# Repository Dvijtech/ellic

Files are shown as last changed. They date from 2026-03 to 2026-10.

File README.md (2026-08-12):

# 🤖 ELLIC 🚶‍♂️

Мы делаем экспериментальный формат медиалиги мех-спорта, где команды строят человекоуправляемые машины и участвуют в боях в дополненной реальности ⚔️

<table> 
  <tr> 
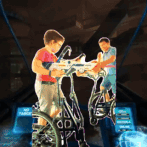
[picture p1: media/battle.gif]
   <td>  </td> 
  </tr> 
</table>

Как BattleBots, только ты внутри мехбота 🤯  
Ты ходишь в механическом экзоскелете и дерёшься в AR.

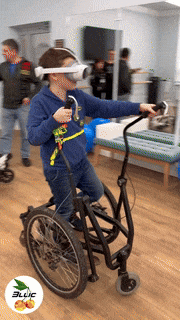
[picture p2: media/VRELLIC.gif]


🔬 Это открытый инженерный эксперимент - смесь спорта, игры и инженерного челленджа 🎮⚙️

Для создания мехботов используется платформа ELLIC, где пилот шагает внутри машины, а сам мехбот по цене сопоставим с электровелосипедом 🚲  

<table>
  <tr>
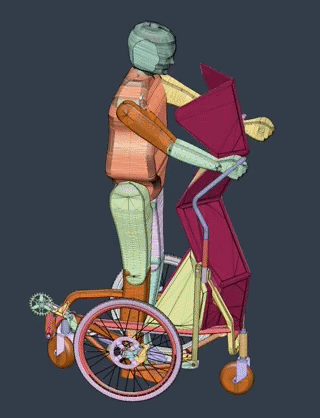
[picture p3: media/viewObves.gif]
    <td></td>
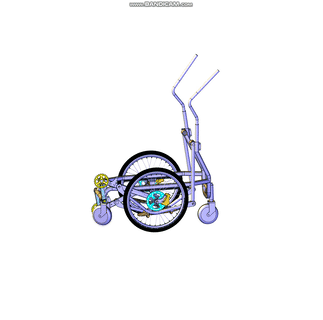
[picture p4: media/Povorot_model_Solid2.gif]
    <td></td>
  </tr>
</table>

В этом репозитории выложены наши разработки, необходимые для создания своего мехбота, и описан экспериментальный формат соревнований в дополненной реальности 📦  

---

# 🧩 Платформа состоит из трёх составляющих:

---

## 1. ⚙️ Физическая платформа. Модели и рабочая документация собраны в ⚙️ [cad/](cad/)

За основу взят эллипс из тренажёрного зала, поставлен на колёса — теперь в нём можно шагать и кататься 🏃‍♂️

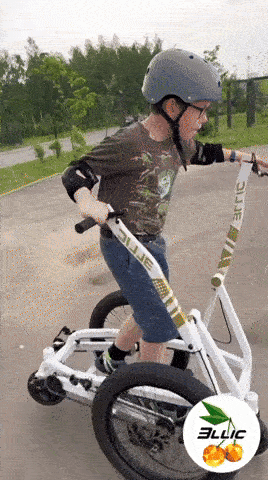
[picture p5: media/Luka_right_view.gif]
walking prototype


- [cad/MECHANISM.md](cad/MECHANISM.md) — описание устройства
  
- [cad/BUILD_ONE](cad/BUILD_ONE.md)  — описание сборки  

Содержимое репозитория:
- a. В репозитории представлены модели Ellic версии 14 в формате Fusion, SolidWorks, STEP  
- b. В папке **Дизайн** представлена модель фронтального обвеса мехбота  
- c. По запросу может быть предоставлена документация для сборки в формате ЕСКД 📄  
- d. Weapon 🔫  
  - виртуальные орудия (как сейчас)  
  - планируются пневматические пушки, стреляющие безопасными снарядами (например, для бассейна) 💦  
  - возможны роборуки для манипуляций, если мы придумаем для них правила 🤖  

---

## 2. 🔌 Электроника. Управляющее программное обеспечение в 📟 [firmware/](firmware/)

- моторы, помогающие движению ⚡  
- датчики момента (усилия на рычагах)  
- энкодер положения вала  
- датчики тока  
- джойстик 🎮  
- система управления (ESP32)  

Содержимое репозитория:
- a. Исходный код прошивки для управления моторами с джойстика 💻  

---

 ## 3. 🥽 [VR / AR лежит здесь:](https://github.com/loguluk/ELLIC)

VR-гарнитура для проведения битвы мехботов в формате дополненной реальности — с виртуальным или реальным противником 👾  

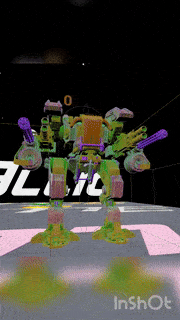
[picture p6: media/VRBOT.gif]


Содержимое репозитория:
- a. Исходный код на Unreal Engine 5.3 (в `.zip`)  
- b. `.apk` для PICO 4 (AR, технология see-through)  
  - бой с виртуальным противником  
  - стрельба ведётся тем же джойстиком, что управляет скутером 🔫  
- c. Папка **Чемп** — проект правил соревнований и безопасности 📜  

---

## Прочие материалы

## 🤖 Моделирование 📊 simulation/

Разделы для моделирования в среде:
- ROS  
- URDF  
- Webots  

Пока там только первые тесты и ничего финального 🧪  

---

## 🔬 Research 📝 [research/](research/) 

Материалы исследований по разным направлениям:
- a. Отчёт по гранту Фонда содействия инновациям  
- b. Медицинские исследования и гипотезы 🧠

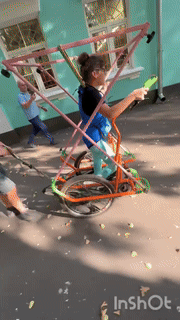
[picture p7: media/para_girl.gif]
 

[История проекта здесь](docs/history/ellicDevHistory.md).

---

## 👥 Community [community/](community/)

[START_A_TEAM](community/START_A_TEAM.md) - принципы формирования и вознаграждения команд медачемпионата

---

# ❓ Зачем тебе сюда

- хочешь построить меха → тебе сюда 🤖  
- хочешь участвовать в шоу → тебе сюда 🎬  
- хочешь просто играть → пока рано ⏳  

---

# ❗ Будет сложно, но мы поможем

В командах приветствуются навыки и оборудование:

- Производство медиаконтента 🎥  
- Знание Unreal Engine или Unity (как плюс, но не обязательно 🎮)  
- Геймдизайн  
- Работа с металлом (резка, сверление, сварка, лазер, гибка), механическая сборка 🔩  
- ESP32 или аналоги  
- знание велокомпонентов (как плюс 🚴)  

---

## ⚠️ Безопасность [chemp/Safety_rules.pdf](CHEMP/Safety_rules.pdf)

Мы тестируем систему и вводим правила безопасности, но это всё ещё экспериментальная техника ⚠️  

Всегда тестируйте:
- на низкой скорости  
- с доступной аварийной остановкой 🛑  

---

Это первый прототип реального мехспорта, и нет гарантии, что всё сразу будет работать идеально, но если это сработает хотя бы частично, вы получите:

- опыт создания реального мехбота: механика, электроника и интеграция с VR 🤖  
- эмоции от управления реальным мехом в бою 🔥  
- место в создании нового медиапродукта на стыке MEDIA – STEM – VR 🚀  

---

# 🎯 Цель

Сформировать в 2026 году 3–4 команды и провести экспериментальный медиачемпионат битвы мехботов:
проект правил здесь [chemp/](CHEMP/)

- чемпионат на вылет  
- 2 меха на спортивной площадке  
- бой в дополненной реальности  
- параллельная трансляция:  
  - физического мира  
  - AR-сцены 📡  

Мы можем предоставить готовые машины для соревнований. Машины могут быть доработаны командами по согласованному регламенту (мы за интересный и зрелищный движ) 😎  

[**MANUAL**](docs/Manual_EllicV14_EN.pdf)

Команды могут строить мехботов самостоятельно. При необходимости мы можем предоставить отдельные сложные детали (рамы, тяги, рычаги) 🏗️  
[cad/BUILD_ONE](cad/BUILD_ONE.md) 

---

## 🚀 Как вписаться без боли

**Быстрый вход (без сборки меха):**

- мы даём готовые машины  
- можно прийти и тестировать  
- можно просто участвовать как пилот 🧑‍🚀  
- можно зайти как команда без инженерки  

Смотри подробнее в [community/START_A_TEAM](community/START_A_TEAM.md) 📄  

---

## 🎁 Что ты реально получишь

- участие в первом прототипе мехспорта  
- видео / медиа с боя 🎥  
- опыт пилотирования меха  
- возможность стать частью команды-основателя 🤝  

---

## 📫 Контакты

Я — Дмитрий Логунов. Раньше занимался автоматизацией в госсекторе и промышленности. Несколько лет со своими сыновьями я делаю Ellic — платформу, на которой человек шагает внутри машины 🤖  

Это не идеальная система и не готовый продукт, а живая разработка, которую мы ведём прямо сейчас 🔧  

Проект развивается в рамках ООО «Движ.Тех» — небольшой компании, занимающейся образовательной робототехникой и экспериментальными платформами 🏢  

Проект поддержан Фондом содействия инновациям 💡  

📧 dselog@gmail.com

[START_A_TEAM](START_A_TEAM.md)

<a href="https://github.com/yourusername/yourrepo/stargazers" target="_blank" style="text-decoration:none;">
  <kbd>⭐ Star the repository</kbd>
</a>

<a href="https://github.com/yourusername/yourrepo/fork" target="_blank" style="text-decoration:none;">
  <kbd>🔧 Fork the project</kbd>
</a>

<a href="https://github.com/yourusername/yourrepo/issues" target="_blank" style="text-decoration:none;">
  <kbd>💡 Open issues with ideas</kbd>
</a>

<a href="https://twitter.com/intent/tweet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" target="_blank" style="text-decoration:none;">
  <kbd>📢 Share the project</kbd>
</a>

---

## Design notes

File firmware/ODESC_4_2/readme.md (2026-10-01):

# ODESC 4.2 — ввод в работу нового ODrive (ELLIC)

Ожидаемо: прошивка **0.5.6**, железо **3.6**, протокол **CAN Simple**, 250000 бит/с, мотор на **axis0**, энкодер — Hall (mode 1, cpr 42).

Файлы в этой папке:

| Файл | Что это |
|---|---|
| `configODRIVE.txt` | **Шаблон** (бэкап рабочего ODrive, node_id=1). Содержит калибровку старого мотора — как есть на новый не заливать |
| `make_config.py` | Делает из шаблона безопасный конфиг для пусконаладки с нужным node_id |
| `backups/` | Итоговые бэкапы каждого откалиброванного ODrive (по одному файлу на плату) |

> В командах ниже объект называется `dev0` (как в прежних заметках). Если в твоём шелле он `odrv0` — подставь.

---

## Почему так, а не «залить как есть»

Конфиг стоит переносить (лимиты, усиления, CAN-рейты, Hall-режим одинаковы для всей партии). Но в нём есть **данные конкретного мотора**: `phase_resistance`, `phase_inductance`, `phase_offset`, `hall_polarity`, флаги `pre_calibrated`. Их надо измерить заново на каждом новом моторе, иначе это риск плохого момента и рывков.

Две ловушки, которые закрывает `make_config.py`:

1. Если флаги `pre_calibrated` остались `True`, `FULL_CALIBRATION_SEQUENCE` **пропустит** калибровку.
2. В шаблоне `startup_closed_loop_control = true` — после рестора плата сразу включит замкнутый контур на чужой калибровке, и мотор может дёрнуться. В конфиге для пусконаладки это выключено, включаем в самом конце.

---

## Перед началом (1 минута)

- Колесо/мотор **без нагрузки**: колесо приподнято, ничего не касается. Калибровка вращает мотор.
- Питание силовое (аккумулятор/блок), не только USB.
- К ПК по USB подключён **один** ODrive. CAN к ESP32 пока **не подключён** (чтобы не было двух плат с одинаковым node_id на шине).
- Версия `odrivetool` та же, что использовалась для `backup-config` на старой плате.

---

## Шаг 1. Прошивка (только для чистой платы)

Через программатор залить `firmware.elf`. 

Затем в `odrivetool`:

```python
print(f"{dev0.fw_version_major}.{dev0.fw_version_minor}.{dev0.fw_version_revision}")   # ждём 0.5.6
print(f"{dev0.hw_version_major}.{dev0.hw_version_minor}")                              # ждём 3.6
print(hex(dev0.serial_number))                                                         # запиши — пригодится для имени бэкапа
```

## Шаг 2. Сделать конфиг под нужный node_id

В терминале (не в odrivetool), в папке с `configODRIVE.txt`:

```
python make_config.py 1     # RIGHT  -> config_node1_commissioning.json
python make_config.py 2     # LEFT   -> config_node2_commissioning.json
```

RIGHT = node_id 1, LEFT = node_id 2 (как в спецификации).

## Шаг 3. Залить конфиг

```
odrivetool restore-config config_node2_commissioning.json
```

Плата перезагрузится и сохранит конфиг. Затем открыть `odrivetool` заново и проверить:
Предупреждения Could not restore ... anticogging.calib_anticogging / cogging_ratio / index безвредны: это служебные поля антикоггинга, которые odrivetool 0.5.4 не умеет записывать через exchange. Антикоггинг ты не используешь (pre_calibrated: false), так что на работу они не влияют. Итоговые строки «Some of the configuration could not be restored» и «Configuration restored» ожидаемы. Второй запуск был не нужен, но ничему не повредил.

Последняя команда restore-config config_node1_commissioning.json внутри IPython (In [2]:) не сработает. Это команда терминала, а не Python. Тебе она там уже не нужна, она выполнена. Строку v в In [1] можно проигнорировать.

Оболочка уже открыта и подключена как dev0, так что команды из readme.md подходят без замены. Дальше, шаг 3 (проверки после рестора), вставь в оболочку:

```python
print(dev0.axis0.config.can.node_id)                       # нужный node_id
print(dev0.can.config.baud_rate)                           # 250000
print(dev0.axis0.config.startup_closed_loop_control)       # False (пока)
print(dev0.axis0.controller.config.vel_limit, dev0.axis0.motor.config.current_lim)   # 2.0 10.0
```

Если `restore-config` ругается на отдельные поля — это обычно read-only параметры, на работу не влияет. Критично, чтобы совпали проверки выше.

## Шаг 4. Калибровка (мотор свободен! минимум 37 вольт и 2 ампера на блоке питания. При малых токах не калибруется!!)

```python
# 4.1 Параметры мотора
dev0.axis0.requested_state = AXIS_STATE_MOTOR_CALIBRATION
# подождать ~5 с, пока мотор пискнет/затихнет
print(dev0.axis0.error, dev0.axis0.motor.error)            # оба 0
print(dev0.axis0.motor.config.phase_resistance, dev0.axis0.motor.config.phase_inductance)
#   ориентир со старой платы: R ≈ 0.176, L ≈ 0.000204 (±~20% нормально; в разы — стоп, проверять фазы)
dev0.axis0.motor.config.pre_calibrated = True

# 4.2 Hall: полярность, затем смещение (мотор повернётся на несколько оборотов)
dev0.axis0.requested_state = AXIS_STATE_ENCODER_HALL_POLARITY_CALIBRATION
dev0.axis0.requested_state = AXIS_STATE_ENCODER_OFFSET_CALIBRATION
# подождать ~10 с
print(dev0.axis0.error, dev0.axis0.encoder.error)          # оба 0
print(dev0.axis0.encoder.config.hall_polarity_calibrated)  # True
print(dev0.axis0.encoder.is_ready)                         # True
print(dev0.axis0.encoder.config.phase_offset_float)        # со старой платы было ≈ 0.50 (ориентир, не критерий)
dev0.axis0.encoder.config.pre_calibrated = True
```

Если после любого шага ошибка не 0: `dump_errors(dev0)`, `dev0.clear_errors()`, проверить подключение фаз и Hall-кабеля, повторить шаг.

## Шаг 5. Проба замкнутого контура (мотор всё ещё свободен)

```python
dev0.axis0.requested_state = AXIS_STATE_CLOSED_LOOP_CONTROL
p = dev0.axis0.encoder.pos_estimate
dev0.axis0.controller.input_pos = p + 0.5      # полоборота вперёд
# …посмотреть, что вращение плавное, без шума и рывков…
dev0.axis0.controller.input_pos = p            # назад
print(dev0.axis0.error, dev0.axis0.motor.error, dev0.axis0.controller.error, dev0.axis0.encoder.error)  # все 0
dev0.axis0.requested_state = AXIS_STATE_IDLE
```

## Шаг 6. Включить автозапуск и сохранить

```python
dev0.axis0.config.startup_closed_loop_control = True
dev0.save_configuration()          # плата перезагрузится, USB-связь пропадёт — это нормально
```

После перезапуска: `print(dev0.axis0.current_state)` → `8` (замкнутый контур), ошибки 0.

## Шаг 7. Бэкап готовой платы

В терминале:

```
odrivetool backup-config backups/ellic_node2_<serial>.json
```

Один файл на каждую плату. `configODRIVE.txt` остаётся шаблоном и не перезаписывается.

## Шаг 8. Подключение к шине и проверка с ESP32

Перед включением: на CAN-шине ровно **две** терминирующие 120 Ω на концах (при выключенном питании между CAN_H и CAN_L ≈ **60 Ω**), общая земля, у каждой платы свой node_id.

Включать **по одной плате**: сначала RIGHT, проверить, потом добавить LEFT. В телеметрии ESP32 для каждого ODrive должно быть:

- `online=1`, `state=8`
- `axis_err=0 motor_err=0 enc_err=0 ctrl_err=0`
- `Vbus` соответствует питанию, `rx` растёт, `rx_fail` не растёт
- при вращении вала колёса идут в зеркально противоположные стороны (знаки `LEFT_WHEEL_SIGN` / `RIGHT_WHEEL_SIGN` из `Config.h`)

Ранее при `node_id=1` наблюдалось странное поведение (`axis_err=0x40`), которого не было при `node_id=2`. Поэтому RIGHT проверяй отдельно и первой; `make_config.py` дополнительно разводит `axis1` node_id (11 / 12), чтобы оси двух плат не пересекались.

---

## Быстрая шпаргалка (нормальный случай)

```
python make_config.py <N>
odrivetool restore-config config_node<N>_commissioning.json
# в odrivetool: проверки шага 3 → калибровка (шаг 4) → проба (шаг 5)
# dev0.axis0.config.startup_closed_loop_control = True ; dev0.save_configuration()
odrivetool backup-config backups/ellic_node<N>_<serial>.json
```

## Чек-лист перед первым запуском ESP32

- [ ] fw 0.5.6, hw 3.6
- [ ] node_id правильный, baud 250000
- [ ] калибровка пройдена, ошибки 0, `pre_calibrated = True` (мотор и энкодер)
- [ ] `startup_closed_loop_control = True`, сохранено
- [ ] бэкап сделан
- [ ] CAN: терминаторы, земля, уникальные node_id
- [ ] `Config.h` проверен (см. ниже)

> Внимание: значения в `Config.h` расходятся со спецификацией — `MOTOR_GEAR_RATIO = 6.4` (в спеке 4.4), `TURN_STEP = 1.0` (в спеке 0.03), `TELEMETRY_PRINT_PERIOD_MS = 1000` (в спеке 100). Если это не осознанные настройки под новую сборку — верни спецификационные значения перед первым запуском колёс. TURN_STEP = 1.0 это целый оборот мотора за один цикл.

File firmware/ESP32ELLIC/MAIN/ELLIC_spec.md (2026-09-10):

# Спецификация системы управления ELLIC (ESP32 + AS5600 + 2×ODrive)

**Прошивка ODrive:** v0.5.6, odesc 4.2

**Протокол связи с ODrive:** CAN Simple

> Это нормативный документ: здесь только то, чему код обязан соответствовать
> (алгоритм, константы, форматы команд, аппаратные подключения, принятые
> архитектурные решения), плюс минимум контекста, без которого правило
> непонятно. Аудиты, открытые вопросы, планы работ и история их исследования
> вынесены в отдельный документ — `ELLIC_worklog.md`. Если раздел здесь
> ссылается на нерешённый вопрос — смотри worklog, не додумывай поведение
> самостоятельно.

---

## 0. Модули и файлы

Система состоит из следующих модулей. Каждый модуль реализован в виде пары файлов .h / .cpp с соответствующим именем. В коде и спецификации используются только эти названия.

| **Модуль** | **Файлы** | **Назначение** |
|---|---|---|
| **Encoder** | Encoder.h / Encoder.cpp | Работа с AS5600: чтение raw-угла, вычисление continuousAngle, обновление в каждом loop() |
| **MotionController** | MotionController.h / MotionController.cpp | Логика движения: расчёт ValDelta, состояние тормозов, вычисление leftWheelDelta / rightWheelDelta, вызов раз в 300 мс |
| **ODriveCAN** | ODriveCAN.h / ODriveCAN.cpp | Единственный модуль, обращающийся к CAN-шине ODrive. Обслуживает два ODrive по их node_id, содержит данные текущей позиции и скорости LEFT WHEEL / RIGHT WHEEL, кэш диагностики и состояние online. |
| **Telemetry** | Telemetry.h / Telemetry.cpp | Сбор снапшотов у всех модулей, буфер логов, вывод в Serial. Никогда не обращается к ODriveCAN напрямую |
| **main.cpp** | main.cpp | Точка входа: setup() и loop(). Связывает модули и вызывает их методы по расписанию |

**Важно:**

- В коде и архитектуре **не используются** другие классы/модули для тех же функций, например OdriveChannel, ODrive, MotorController и т.п.
- ODriveCAN — единственный владелец CAN-шины ODrive. Все обращения к ODrive выполняются через него.
- Telemetry не обращается к ODrive напрямую, а только получает данные через ODriveCAN.
- main.cpp содержит один экземпляр ODriveCAN. ODriveCAN обслуживает два логических канала: RIGHT → node_id = 1; LEFT → node_id = 2.
- Этот раздел является **нормативным**: расхождение фактической структуры кода с данным списком считается нарушением спецификации.

---

## 1. Физическая модель

- Есть один механический вал с датчиком **AS5600** (абсолютный энкодер, 0...360°).
- Вал через шагающий механизм (коленвал → шатуны → тяги → оси колёс на каретках, движущихся по направляющим) связан с двумя мотор-колёсами.
- Каждое мотор-колесо управляется своим **ODrive** (LEFT / RIGHT).
- Левый и правый тормоза позволяют независимо фиксировать соответствующее колесо.
- `MOTOR_GEAR_RATIO = 4.4` — передаточное число редуктора: чтобы колесо на выходе сделало ровно 1 оборот, мотор (вал ODrive) должен провернуться в 4.4 раза больше.
- Разрешение Hall-датчика мотора (42 такта/оборот) в коде **не используется** и для расчётов не нужно.

**Главный принцип:** вал — единственный источник движения. ESP32 сам движение не генерирует. Человек двигает вал → ESP32 пересчитывает это в движение колёс.

---

## 2. Архитектура: общее решение по тормозам + независимые CAN-каналы

ESP32 — один контроллер. Важно не путать два разных уровня независимости:

- **Расчёт приращений (`leftWheelDelta` / `rightWheelDelta`) — НЕ независим по каналам.** Это одно общее решение на каждый цикл управления: оно смотрит на состояние **обоих** тормозов сразу и на общий `Val` (раздел 8) и по результату сразу определяет оба приращения — левое и правое — вместе. Разложить этот шаг на отдельную "левую" и отдельную "правую" логику нельзя: например, при нажатом только левом тормозе именно это единое решение обнуляет `leftWheelDelta` и одновременно выставляет `rightWheelDelta = TURN_STEP × RIGHT_WHEEL_SIGN`.
- **Обмен с RIGHT и LEFT выполняется через общий модуль ODriveCAN, но логические каналы RIGHT и LEFT остаются независимыми.** RIGHT определяется node_id = 1. LEFT определяется node_id = 2. Ошибка или отсутствие ответа RIGHT не блокирует работу LEFT. Ошибка или отсутствие ответа LEFT не блокирует работу RIGHT.

**Схема (как в исходном документе):**

```
AS5600
│
▼
Encoder::update() (в loop(), непрерывно)
│
▼
continuous angle accumulation
│
▼
каждые CONTROL_PERIOD_MS:
MotionController.update()
│
▼
общее решение по ОБОИМ тормозам + Val (раздел 8):
BOTH BRAKES / NO BRAKES / ONE BRAKE (+ TURN_ZONE)
│
▼
вычислены СРАЗУ ОБА: LeftWheelDelta и RightWheelDelta
│
┌────────┴────────┐ ← дальше каналы независимы
▼                 ▼
LEFT CHANNEL      RIGHT CHANNEL
│                 │
▼                 ▼
f 0 → currentPos  f 0 → currentPos
│                 │
▼                 ▼
p 0 (currentPos+Δ) p 0 (currentPos+Δ)
│                 │
▼                 ▼
ODrive L          ODrive R
│                 │
▼                 ▼
LEFT MOTOR        RIGHT MOTOR
```

**Та же схема в формате mermaid:**

```mermaid
flowchart TD
    AS5600 --> ENC["Encoder::update()<br/>(в loop(), непрерывно)"]
    ENC --> ACC[continuous angle accumulation]
    ACC --> MC["каждые CONTROL_PERIOD_MS:<br/>MotionController.update()"]
    MC --> DEC["общее решение по ОБОИМ тормозам + Val (раздел 8):<br/>BOTH BRAKES / NO BRAKES / ONE BRAKE (+ TURN_ZONE)"]
    DEC --> BOTH["вычислены СРАЗУ ОБА:<br/>LeftWheelDelta и RightWheelDelta"]
    BOTH --> LEFT["LEFT CHANNEL<br/>(дальше каналы независимы)"]
    BOTH --> RIGHT["RIGHT CHANNEL<br/>(дальше каналы независимы)"]
    LEFT --> LF["f 0 → currentPos"]
    RIGHT --> RF["f 0 → currentPos"]
    LF --> LP["p 0 (currentPos+Δ)"]
    RF --> RP["p 0 (currentPos+Δ)"]
    LP --> OL[ODrive L]
    RP --> OR[ODrive R]
    OL --> LM[LEFT MOTOR]
    OR --> RM[RIGHT MOTOR]
```

---

## 3. Переменные и терминология

Используем только те объекты/переменные, которые реально существуют в коде.

| Объект | Переменная | Смысл |
|---|---|---|
| Val | raw-угол AS5600 | 0...360°, читается напрямую с датчика |
| Val | continuous angle | накопленный (безразрывный) угол вала |
| Val | `ValDelta` | изменение continuous angle между двумя циклами `MotionController.update()` |
| LeftWheel | `leftWheelDelta` | приращение, которое отправляется на ODrive L (в оборотах вала мотора ODrive, до редуктора) |
| RightWheel | `rightWheelDelta` | приращение, которое отправляется на ODrive R |
| ODrive (L/R) | `currentPosition` | позиция, читаемая с ODrive командой `f 0` перед каждой отправкой |

Накопленной цели (target) в ESP32 **нет** — новая команда всегда строится от позиции, реально считанной у ODrive в этом цикле. Если очередная дельта не была учтена (пропуск цикла и т.п.), она просто теряется — накопления ошибки не происходит.

---

## 4. Аппаратные подключения (ESP32)

**AS5600 (I²C):**

| Сигнал | Пин |
|---|---|
| SDA | GPIO21 |
| SCL | GPIO22 |
| I²C clock | 50 кГц (`Wire.setClock(50000)`, значение по умолчанию) |

**Тормоза:**

| Сигнал | Пин | Режим |
|---|---|---|
| LEFT_BRAKE_PIN | GPIO32 | `INPUT_PULLUP` |
| RIGHT_BRAKE_PIN | GPIO33 | `INPUT_PULLUP` |

Тормоз считается **нажатым** при `digitalRead(pin) == LOW` (активный уровень — LOW, за счёт pull-up).

**CAN:**

- ESP32: встроенный TWAI controller
- CAN transceiver: SN65HVD230
- CAN-шина: CAN_H / CAN_L
- Оба ODrive подключены к одной физической CAN-шине.
- ODrive RIGHT: node_id = 1
- ODrive LEFT: node_id = 2

Пины TWAI (см. также раздел 15, "Итого зафиксировал в спецификации"):

| Сигнал | Пин |
|---|---|
| CAN TX | GPIO16 |
| CAN RX | GPIO17 |

CAN bitrate = 250000 бит/с.

---

## 5. Константы

| Константа | Значение | Назначение |
|---|---|---|
| `CONTROL_PERIOD_MS` | **300 мс** | период вызова `MotionController.update()` |
| `MOTOR_GEAR_RATIO` | 4.4 | передаточное число редуктора |
| `TURN_ZONE_DEG` | 10.0° | ширина зоны вокруг 180° и 0°/360°, где разрешён поворот |
| `TURN_STEP` | 0.03 (оборота мотора ODrive) | величина приращения противоположного колеса при повороте |
| `LEFT_WHEEL_SIGN` | +1.0 | знак канала LEFT |
| `RIGHT_WHEEL_SIGN` | −1.0 | знак канала RIGHT (моторы установлены зеркально) |
| `Telemetry.periodMs` | 150 мс | период запуска цикла сбора телеметрии (см. раздел 12) |
| `Telemetry.printPeriodMs` | 100 мс | период вывода в Serial (~10 Гц) |
| `CAN_NODE_STALE_MS` | 300 мс | время ожидания CAN |

---

## 6. Вычисление ValDelta

### 6.1. На уровне энкодера

(`Encoder::update()`, вызывается в каждом проходе `loop()`, без привязки к `CONTROL_PERIOD_MS`)

```
delta = currentRawAngle − previousRawAngle
если delta > 180°: delta -= 360°
если delta < −180°: delta += 360°
continuousAngle += delta
```

Коррекция перехода через 0°/360° обязательна, иначе переход трактуется как скачок на ~360° вместо реального малого перемещения:

- 359° → 1° ⇒ +2° (а не −358°)
- 1° → 359° ⇒ −2° (а не +358°)

### 6.2. На уровне контроллера движения

(`MotionController.update()`, раз в `CONTROL_PERIOD_MS`)

```
ValDelta = ValContinuousAngle_now − ValContinuousAngle_previous_control_cycle
```

`ValDelta` — это суммарное изменение вала **между двумя циклами управления** (каждые 300 мс), а не между двумя соседними чтениями AS5600 (они происходят чаще).

### 6.3. Обработка ошибок AS5600

При ошибке чтения I²C с AS5600 (`Wire.requestFrom()` возвращает менее 2 байт):

- `continuousAngle` НЕ обновляется;
- `previousRawAngle` НЕ обновляется;
- функция возвращает последнее валидное значение датчика;
- ошибка логируется в `Telemetry` с уровнем `LogLevel::WARNING`.

Ошибка чтения не должна интерпретироваться как изменение угла. Значение `0°` является валидным значением AS5600 и НЕ используется как признак ошибки чтения.

Ошибки AS5600 не обрабатываются автоматически системой — ни как аварийная остановка, ни как сброс `continuousAngle`, ни как переход в отдельное аварийное состояние. Обоснование: управление построено на приращениях (`ValDelta`), а не на абсолютном значении `continuousAngle` как команде положения. Единичный сбой чтения не накапливается:

- при ошибке чтения `continuousAngle` остаётся неизменным;
- `previousRawAngle` остаётся неизменным;
- после восстановления связи следующее валидное чтение корректно продолжает накопление угла;
- отдельного ложного приращения из-за самого факта ошибки чтения не возникает.

При этом система не выполняет автоматическую коррекцию возможного медленного дрейфа `continuousAngle`, если датчик при физически неподвижном вале выдаёт изменяющиеся валидные значения. Такой дрейф потенциально может приводить к соответствующему `ValDelta` и, следовательно, к движению колёс. Этот риск принят как осознанное ограничение архитектуры: автоматической компенсации дрейфа, фиксации нулевой точки, остановки обоих ODrive или перехода в отдельное аварийное состояние не предусмотрено. Контроль в такой ситуации осуществляется пилотом через тормоза (раздел 8) и выключение питания.

---

## 7. Базовое (нормальное) движение — если ни один тормоз не нажат

```
leftWheelDelta  = ValDelta × MOTOR_GEAR_RATIO / 360 × LEFT_WHEEL_SIGN
rightWheelDelta = ValDelta × MOTOR_GEAR_RATIO / 360 × RIGHT_WHEEL_SIGN
```

Знаки каналов компенсируют зеркальную установку моторов: при одном и том же `ValDelta` колёса должны крутиться в геометрически противоположные стороны.

---

## 8. Логика тормозов и поворота

Порядок проверок на каждом цикле **фиксирован**:

1. оба тормоза нажаты
2. ни один тормоз не нажат
3. нажат только левый тормоз
4. нажат только правый тормоз

В ветках "только один тормоз" дополнительно проверяется, находится ли Val в `TURN_ZONE`.

### 8.1. Зона поворота (TURN_ZONE)

Две зоны шириной `TURN_ZONE_DEG` (10°) вокруг опорных точек 180° и 0°/360°:

- зона у 180°: **170°...190°**
- зона у 0°/360°: **350°...360°/0°...10°** (корректно оборачивается через 0°)

Примеры (при TURN_ZONE_DEG = 10°):

- 358° — внутри зоны; 2° — внутри зоны
- 349° — вне зоны; 11° — вне зоны

### 8.2. Полный алгоритм

```
1. BOTH BRAKES (leftBrake && rightBrake)
   → CALM

2. NO BRAKES (!leftBrake && !rightBrake)
   → NORMAL MOTION (раздел 7)

3. LEFT BRAKE ONLY (leftBrake && !rightBrake)
   → processLeftBrake()
   ├─ Val вне TURN_ZONE → CALM
   └─ Val в TURN_ZONE:
        leftWheelDelta = 0
        rightWheelDelta = TURN_STEP × RIGHT_WHEEL_SIGN

4. RIGHT BRAKE ONLY (rightBrake && !leftBrake)
   → processRightBrake()
   ├─ Val вне TURN_ZONE → CALM
   └─ Val в TURN_ZONE:
        leftWheelDelta = TURN_STEP × LEFT_WHEEL_SIGN
        rightWheelDelta = 0
```

**Та же схема в формате mermaid (как приведено в исходном документе):**

```mermaid
graph TD
A[MotionController.update()] --> B{оба тормоза?}
B -->|YES| C[CALM]
B -->|NO| D{есть тормоз?}
D -->|NO| E[NORMAL]
D -->|YES| F{какой?}
F -->|LEFT BRAKE| G[processLeftBrake]
F -->|RIGHT BRAKE| H[processRightBrake]
G --> I{TURN_ZONE?}
I -->|YES| J[TURN]
I -->|NO| K[CALM]
H --> L{TURN_ZONE?}
L -->|YES| M[TURN]
L -->|NO| N[CALM]
```

### 8.3. Сводная таблица переходов

| anyBrake | bothBrakes | Val в TURN_ZONE | Результат |
|---|---|---|---|
| нет | — | — | NORMAL (раздел 7) |
| да | да | — | CALM |
| да | нет | нет | CALM |
| да | нет | да | приращение противоположного колеса на `TURN_STEP × соответствующий *_WHEEL_SIGN` |

### 8.4. CALM

`CALM` формирует `leftWheelDelta = 0` и `rightWheelDelta = 0`, но это **не означает отсутствие команды на ODrive**: команда всё равно отправляется (см. раздел 9) — фактически ODrive получает повторно свою текущую позицию как новую цель. Отдельного state machine для CALM нет: на каждом новом цикле `MotionController.update()` режим определяется заново, исходя из текущих входов (тормоза + положение Val).

---

## 9. Формирование команды на ODrive

Для **каждого** колеса, на каждом цикле управления, независимо от режима (NORMAL / CALM / TURN):

```
1. Получить текущую позицию LEFT WHEEL или RIGHT WHEEL (f0)
2. Вычислить: newPosition (P0) = currentPosition + соответствующий wheelDelta
3. Отправить абсолютную позицию LEFT WHEEL или RIGHT WHEEL.
```

- `wheelDelta` — это `leftWheelDelta` или `rightWheelDelta`, рассчитанные по правилам разделов 7/8.
- Логика f 0 → currentPosition → p 0 сохраняется. В текущей архитектуре: f 0 — логическое получение текущей позиции колеса; p 0 — логическая отправка абсолютной позиции колеса. При использовании CAN физическая реализация этих операций выполняется через CAN Simple: (f 0: Get Encoder Estimates), (p 0: Set Input Pos).

Get Encoder Estimates передаёт:

- Pos_Estimate — позиция соответствующего WHEEL в turns.
- Vel_Estimate — скорость соответствующего WHEEL в turns/s.

ESP32 принимает оба значения как float. Для CAN Simple Get Encoder Estimates имеет command ID `0x09` и payload из двух float: position и velocity.

Физически по CAN используется CAN Simple команда Set Input Pos. Логически операция соответствует `p 0 <newPosition>`. Set Input Pos имеет CAN command ID `0x0C`; позиция передаётся как float в turns.

- Команда `move_incremental` **не используется** — управление полностью построено на чтении фактической позиции (`Get Encoder Estimates`) и отправке абсолютной цели (`Set Input Pos`).
- Накопленного target в MotionController нет: каждая новая команда строится от последней валидной позиции LEFT WHEEL / RIGHT WHEEL, полученной ODriveCAN от соответствующего ODrive.
- **Если чтение позиции ODrive (`Get Encoder Estimates`) завершилось ошибкой — команда `Set Input Pos` для этого колеса в этом цикле не отправляется.** Второе колесо на это не влияет (каналы независимы).
- Все обращения к ODrive в этом разделе идут через `ODriveCAN` (см. раздел 14) — не напрямую.

Позиция энкодера ВАЛА и позиция колеса — разные величины:

- **Энкодер ВАЛА**: AS5600, используется MotionController для расчёта continuousAngle, ValDelta, leftWheelDelta и rightWheelDelta.
- **LEFT WHEEL**: позиция энкодера ODrive левого колеса, получаемая от ODrive LEFT.
- **RIGHT WHEEL**: позиция энкодера ODrive правого колеса, получаемая от ODrive RIGHT.

leftWheelDelta и rightWheelDelta всегда являются приращениями, рассчитанными из движения энкодера ВАЛА.

---

## 10. Конфигурация ODrive

Есть **два независимых механизма** конфигурации. Важно не путать их: один отключён, второй активен и реально выполняется во время работы системы.

### 10.1. Явный `configure()` из `setup()` — ОТКЛЮЧЁН

В `main.cpp` вызовы закомментированы:

```cpp
// leftODrive.configure();
// rightODrive.configure();
```

Этот путь не выполняется при текущей сборке. Если бы он был включён, это был бы разовый блокирующий вызов при старте.

### 10.2. Конфигурация ODrive при работе по CAN

В runtime ESP32 не выполняет ASCII UART-конфигурацию ODrive. Параметры ODrive, необходимые для работы системы и CAN Simple, должны быть предварительно настроены и сохранены в конфигурации каждого ODrive до запуска ELLIC.

ESP32 в runtime не отправляет команды вида `w ...`, `r ...`, `f ...`, `p ...` для конфигурации ODrive.

Проверка текущего состояния ODrive выполняется по CAN через Heartbeat и другие доступные CAN-данные.

Автоматическая повторная конфигурация ODrive при потере связи не выполняется.

### 10.3. CAN node_id

Для работы двух ODrive на одной CAN-шине используются разные node_id:

- RIGHT: node_id = 1
- LEFT: node_id = 2

node_id каждого ODrive должен быть сохранён в его конфигурации до запуска системы ELLIC.

### 10.4. Heartbeat CAN Simple

CAN ID: `(node_id << 5) | 0x01`

Heartbeat принимается отдельно для RIGHT и LEFT.

Для ODrive v0.5.6 Heartbeat содержит:

- Axis_Error
- Axis_State
- Motor_Error_Flag
- Encoder_Error_Flag
- Controller_Error_Flag
- Trajectory_Done_Flag

Heartbeat используется для получения axisError, axisState и состояния выполнения процедуры.

Heartbeat не используется как источник controller.error или motor.error. Эти ошибки получают отдельными CAN сообщениями.

---

## 11. Цикл `loop()` и тайминги

```
loop()
│
├── encoder.update() ← выполняется на каждом проходе, без периода
│
├── updateConfigure()
│
├── прошло CONTROL_PERIOD_MS (300 мс)?
│    └── YES → MotionController.update() (разделы 6.2–9)
│
└── telemetry.update() ← собственный период, см. раздел 12
```

**Та же схема в формате mermaid:**

```mermaid
flowchart TD
    L0([loop]) --> A["encoder.update()<br/>выполняется на каждом проходе, без периода"]
    L0 --> B["updateConfigure()"]
    L0 --> C{"прошло CONTROL_PERIOD_MS (300 мс)?"}
    C -->|YES| D["MotionController.update()<br/>(разделы 6.2–9)"]
    L0 --> E["telemetry.update()<br/>собственный период, см. раздел 12"]
```

Следствия для отладки:

- AS5600 и накопленный угол обновляются **постоянно** (каждый проход `loop()`);
- решение "куда двигать колёса" принимается только раз в 300 мс;
- если между вызовами `MotionController.update()` вал успел провернуться на большой угол, это всё равно будет учтено целиком в одном `ValDelta` — потерь на уровне энкодера нет, но управление дискретно с шагом 300 мс.

---

## 12. Telemetry: сбор состояния и логирование (единый компонент)

`Telemetry` — единственный модуль, отвечающий за вывод в Serial. Он не управляет движением и не хранит данные постоянно между циклами — он либо **забирает** снапшот у владельца данных (PULL), либо **принимает** событие от любого модуля в момент, когда оно произошло (PUSH). Это два независимых пути внутри одного класса.

### 12.0. CAN-сообщения диагностики, используемые Telemetry

**Get Encoder Estimates:**

- CAN ID: `(node_id << 5) | 0x09`
- Payload: Pos_Estimate, Vel_Estimate
- ODrive отправляет это сообщение циклически.
- Pos_Estimate сохраняется в кэше ODriveCAN как текущая позиция соответствующего WHEEL.
- Vel_Estimate сохраняется как текущая скорость соответствующего WHEEL.

**Get Bus Voltage Current:**

- CAN ID: `(node_id << 5) | 0x17`
- Payload: Bus_Voltage, Bus_Current (оба значения — float)
- ODriveCAN сохраняет их в кэше соответствующего ODrive.
- Telemetry получает их через getSnapshot().
- `bus_vi_rate_ms = 100`
- `iq_rate_ms = 100`

### 12.1. PULL-путь: периодический сбор состояния

Telemetry не обращается к ODrive напрямую. Она получает данные только из кэша ODriveCAN через getSnapshot(). ODriveCAN обновляет диагностический кэш из входящих CAN-кадров LEFT WHEEL / RIGHT WHEEL.

Основные данные, используемые системой LEFT WHEEL / RIGHT WHEEL:

- Heartbeat: axisError, axisState, Procedure_Result, Trajectory_Done_Flag;
- Get Encoder Estimates: Pos_Estimate, Vel_Estimate.

Pos_Estimate используется как текущая позиция соответствующего WHEEL, Vel_Estimate — как текущая скорость соответствующего WHEEL.

Telemetry только читает уже полученный кэш через getSnapshot(). Telemetry не отправляет диагностические запросы к ODrive. Фоновая диагностика — второстепенная задача и не должна задерживать MoveWheel (см. раздел 14). Telemetry с этим не считается: она просто читает то, что уже есть в кэше на момент своего collect().

- **collect()** — раз в `Telemetry.periodMs = 150 мс`. Забирает снапшот у каждого владельца данных через единый метод getSnapshot(): Encoder, MotionController, ODriveCAN (LEFT), ODriveCAN (RIGHT). Результат складывается в TelemetrySample (раздел 12.3) — это транзитный объект, пересобираемый заново на каждом цикле, а не постоянное хранилище.
- **printScheduled()** — раз в `Telemetry.printPeriodMs = 100 мс`. Печатает последний собранный TelemetrySample плюс накопленные с прошлой печати события уровня INFO/WARNING (раздел 12.2).

Важно: Encoder.getSnapshot() и MotionController.getSnapshot() читают данные из RAM владельца **мгновенно**, без CAN. ODriveCAN.getSnapshot() тоже не обращается к CAN в момент вызова — он отдаёт значения из **своего кэша**, заполняемого фоновой диагностикой, описанной выше.

OdriveSnapshot получает метку diagnosticsTimestampMs, которая проставляется при каждом успешном получении диагностического значения (любого из семи, не только последнего в круге). Метка используется только для диагностики в Serial-выводе и не влияет на управление мотором. Устаревание диагностического кэша само по себе не является ошибкой управления и не влияет на отправку команд движения. Автоматический порог устаревания не вводится.

**Примечание: соотношение частоты collect() и частоты обновления диагностического кэша.** Telemetry.collect() (150 мс) и printScheduled() (100 мс) синхронизированы с потребностями Encoder и MotionController, чьи снапшоты меняются быстро и читаются мгновенно из RAM.

### 12.2. PUSH-путь: логи

```cpp
enum class LogLevel { INFO, WARNING, ERROR, CRITICAL };
void Telemetry::log(LogLevel level, const char* module, const char* msg);
```

- Вызывается из **любого** модуля в момент события: `main.cpp` (инициализация), `Encoder`, `MotionController`, `ODriveCAN` (переход в offline, ошибка связи и т.п.).
- `ERROR` / `CRITICAL` — печатаются в Serial **немедленно**, синхронно внутри вызова `log()`, минуя расписание.
- `INFO` / `WARNING` — складываются в кольцевой буфер фиксированного размера и печатаются на ближайшем `printScheduled()` (раздел 12.1).
- Фильтрация по уровню — простой порог `minLevel`, ниже которого события не попадают даже в буфер.

### 12.3. `TelemetrySample` и владение данными

```cpp
struct EncoderSnapshot { float rawAngle, continuousAngle, lastDelta; };

struct MotionSnapshot {
    float valDelta, leftWheelDelta, rightWheelDelta;
    enum class Mode { NORMAL, CALM, TURN } mode;
    bool leftBrake, rightBrake, inTurnZone;
};

struct OdriveSnapshot {
    bool online;
    int axisState, axisError, motorError, controllerError;
    float Iq, Vq, velEstimate;
    uint32_t txCount, rxCount, rxFailCount;
    // last_tx / last_rx / last_cmd — по необходимости
};

struct TelemetrySample {
    EncoderSnapshot encoder;
    MotionSnapshot motion;
    OdriveSnapshot left;
    OdriveSnapshot right;
};
```

| Модуль | Владеет | Отдаёт через |
|---|---|---|
| `Encoder` | raw-угол, continuous angle, последняя дельта | `getSnapshot()` |
| `MotionController` | ValDelta, wheelDelta, режим, состояние тормозов | `getSnapshot()` |
| `ODriveCAN` (L/R) | online/state/errors, счётчики циклов обмена, fail, также важно зафиксировать CAN message IDs для Iq, Vq, vel и получать их | `getSnapshot()` (из кэша) |
| `Telemetry` | ничего постоянно — только текущий `TelemetrySample` и буфер логов | — |

Ни один модуль не хранит копию чужих данных — `Telemetry` не держит собственные поля вроде `leftCurrent`/`rightVelocity` между циклами, она пересобирает `TelemetrySample` заново при каждом `collect()`.

### 12.4. Роль `main.cpp`

`main.cpp` не решает, что именно передавать в `Telemetry`. Набор источников для `collect()` фиксирован в коде самого `Telemetry` (прямые вызовы `encoder.getSnapshot()` и т.д.) — `main.cpp` только вызывает `telemetry.log(...)` для собственных сообщений (например, при инициализации) и раз в `loop()` вызывает `telemetry.update()`.

### 12.5. Serial-вывод

```
ENC raw / ENC cont / ENC delta
BRAKE left/right/both
TURN zone
MOTION mode
WHEEL delta left/right
ODRIVE LEFT / ODRIVE RIGHT:
    online, state, axis_error, motor_error, controller_error,
    tx, rx, rx_fail
```

плюс накопленные с прошлой печати события INFO/WARNING, и, отдельно, немедленно — события ERROR/CRITICAL в момент их возникновения.

Все обращения к ODrive, стоящие за этим разделом, идут только через `ODriveCAN` (раздел 14) — `Telemetry` сама с CAN не работает.

---

## 13. Обработка ошибок связи с ODrive

Связь по CAN с каждым ODrive обслуживается независимо (раздел 14).

- ODrive считается online, если от соответствующего node_id получен валидный CAN кадр и время с последнего такого кадра не превышает CAN_NODE_STALE_MS.
- Если валидный CAN кадр от ODrive не поступал дольше CAN_NODE_STALE_MS = 300 ms, ODrive считается offline.
- Получение следующего валидного CAN кадра автоматически восстанавливает online = true.
- **Счётчики** на каждый ODrive: txCount, rxCount, rxFailCount, а также lastTxCommand, lastRxCommand — используются только для диагностики (вывод в Serial), не влияют на логику управления.
- **Диагностические регистры**, читаемые с ODrive: axis0.current_state, axis0.error, axis0.motor.error, axis0.controller.error — тоже только для вывода, не парсятся автоматически в коде управления (раздел 13.5).
- **Единственное фактическое влияние ошибки на управление**: Если текущая позиция соответствующего WHEEL недоступна или считается устаревшей, новая команда абсолютной позиции для этого WHEEL не отправляется. Второе WHEEL при этом продолжает работать независимо. Канал (LEFT/RIGHT) не влияет на другой канал.

### 13.2. Watchdog ODrive (axis0.config.enable_watchdog) — принятое решение

**Watchdog не включается.** Основание: момент отказа (замирание колеса на последней скомандованной позиции) наступает мгновенно в момент сбоя, независимо от наличия watchdog — таймаут watchdog определяет только момент, когда это застывшее колесо **дополнительно** потеряет удержание и уйдёт в IDLE (свободное вращение). Для целей безопасности пилота watchdog ничего не решает — он не может предотвратить сам момент остановки и не умеет плавно снижать усилие (жёсткий переход в IDLE по истечении таймаута — это всё, что умеет прошивка 0.5.6).

**Принятое поведение при потере управления — вечное удержание последней позиции**, а не снятие усилия. Причина: у механизма нет отдельного механического тормоза, управляемого независимо от ODrive (тормоза в разделе 8 — это органы управления поворотом, которые читает ESP32, а не стопор колеса); при потере усилия на уклоне ELLIC может покатиться. Держание позиции признано более безопасным сценарием по умолчанию, чем свободное вращение.

Watchdog с большим таймаутом (~60 с) как энергетическая/тепловая подстраховка на случай, если устройство осталось без присмотра при активном удержании — рассмотрен и **отклонён**, не используется.

### 13.3. Реакция на offline одного ODrive

ODrive считается online, если от соответствующего node_id получен валидный CAN-кадр и время с момента последнего валидного кадра не превышает CAN_NODE_STALE_MS.

Если валидных CAN-кадров от ODrive нет дольше CAN_NODE_STALE_MS = 300 мс, ODrive считается offline. Получение следующего валидного CAN-кадра автоматически восстанавливает online = true.

RIGHT и LEFT обрабатываются независимо.

### 13.5. Реакция на ошибки состояния ODrive (axis0.error, motor.error, controller.error)

Эти ошибки читаются фоново (раздел 12.1) и выводятся в телеметрию (разделы 12.2, 12.5). Автоматических действий (остановка канала, сброс, переход в отдельное состояние) **не предусмотрено**.

Причины:

- ошибки ODrive в штатной работе возникают редко и чаще всего связаны с настройкой или внешними факторами (питание, перегрузка);
- оператор контролирует систему через Serial и тормоза;
- введение автоматической реакции усложняет код и может приводить к ложным срабатываниям;
- при потере управления ODrive самостоятельно переходит в IDLE или DISARMED в соответствии со своими внутренними защитами — это уже достаточный уровень безопасности.

Если по итогам эксплуатации будет выявлена необходимость автоматической реакции — решение будет принято отдельно, с внесением изменений в данный раздел.

### 13.6. Восстановление связи после offline

offline — только диагностическое состояние канала связи, не отдельное состояние управления ODrive.

Если после online = false от соответствующего ODrive снова получен валидный CAN-кадр:

- online немедленно устанавливается в true;
- дальнейшая работа канала продолжается в штатном режиме;
- отдельная процедура восстановления не требуется;
- второе колесо при этом не останавливается и не влияет на восстановление первого.

Явно **не** происходит автоматически:

- повторная конфигурация ODrive не выполняется;
- configure() не вызывается автоматически;
- sendConfigCommands() не вызывается автоматически.

Перезапуск конфигурации ODrive (раздел 10) — отдельная операция, не часть механизма восстановления связи.

Восстановление online определяется исключительно фактом получения валидного CAN-кадра от соответствующего ODrive — не временем, прошедшим с последней ошибки, не количеством успешных попыток подряд сверх одной.

rxFailCount при восстановлении связи **не сбрасывается** и продолжает содержать накопленное за текущую сессию количество ошибок (раздел 13.4).

**Схема (как в исходном документе):**

```
online = false
│
│ успешный ответ
▼
online = true
```

**Та же схема в формате mermaid:**

```mermaid
stateDiagram-v2
    state "online = false" as offline
    state "online = true" as online
    [*] --> offline
    offline --> online: успешный ответ (валидный CAN-кадр)
    online --> offline: нет валидных кадров дольше CAN_NODE_STALE_MS
```

---

## 14. Модуль ODriveCAN

### 14.1. Работа ODriveCAN

ODriveCAN является единственным владельцем CAN-интерфейса ODrive. CAN работает асинхронно.

На каждом проходе loop() ODriveCAN:

1. принимает все доступные CAN-кадры;
2. определяет node_id отправителя;
3. определяет логический канал RIGHT или LEFT;
4. обрабатывает Heartbeat;
5. обновляет axisState и axisError;
6. обновляет Pos_Estimate и Vel_Estimate;
7. обновляет timestamp последнего валидного кадра;
8. при необходимости отправляет Set Input Pos.

RIGHT: node_id = 1. LEFT: node_id = 2.

Ошибка или отсутствие данных одного ODrive не блокирует обработку второго ODrive.

### 14.2. MoveWheel

На каждом цикле управления MotionController формирует leftWheelDelta и rightWheelDelta.

Для каждого WHEEL независимо:

1. используется последняя валидная позиция соответствующего WHEEL;
2. вычисляется: newPosition = currentPosition + wheelDelta
3. отправляется Set Input Pos с абсолютной позицией newPosition.

Если актуальная позиция соответствующего WHEEL недоступна или считается устаревшей, Set Input Pos для этого WHEEL в этом цикле не отправляется. Второе WHEEL продолжает работать независимо.

### 14.3. Приоритет движения

Обработка входящих CAN-кадров не должна блокироваться телеметрией или выводом в Serial.

MoveWheel не должен ждать диагностического ответа от ODrive.

Telemetry только читает кэш ODriveCAN и не выполняет CAN-запросов.

---

## 15. Итоговая схема алгоритма (сквозная)

```
AS5600
│
▼
Encoder::update() ← каждый проход loop()
│
▼
continuous angle accumulation
│
▼
каждые 300 мс: MotionController.update()
│
┌──────┴──────┐
│             │
BRAKES?    TURN ZONE?
│             │
└──────┬──────┘
       ▼
вычислить leftWheelDelta / rightWheelDelta
│
┌──────────┼──────────┐
│          │           │
NORMAL   CALM        TURN
(разд.7) (разд.8.4)  (разд.8.2)
│          │           │
└──────────┼──────────┘
           ▼
для КАЖДОГО ODrive независимо, через ODriveCAN:
│
▼
f 0 → currentPosition
│  │
│  (ошибка? → пропустить это колесо в этом цикле)
▼
newPosition = currentPosition + wheelDelta
│
▼
p 0 <newPosition>
│
▼
ODrive → MOTOR

Физически:
f 0 → последняя Pos_Estimate из CAN Get Encoder Estimates
p 0 → CAN Simple Set Input Pos
```

**Та же схема в формате mermaid:**

```mermaid
flowchart TD
    S1[AS5600] --> S2["Encoder::update()<br/>каждый проход loop()"]
    S2 --> S3[continuous angle accumulation]
    S3 --> S4["каждые 300 мс:<br/>MotionController.update()"]
    S4 --> S5{"BRAKES? / TURN ZONE?"}
    S5 --> S6["вычислить leftWheelDelta / rightWheelDelta"]
    S6 --> N["NORMAL (разд. 7)"]
    S6 --> C["CALM (разд. 8.4)"]
    S6 --> T["TURN (разд. 8.2)"]
    N --> S7["для КАЖДОГО ODrive независимо, через ODriveCAN"]
    C --> S7
    T --> S7
    S7 --> S8["f 0 → currentPosition<br/>(ошибка? → пропустить это колесо в этом цикле)"]
    S8 --> S9["newPosition = currentPosition + wheelDelta"]
    S9 --> S10["p 0 &lt;newPosition&gt;"]
    S10 --> S11["ODrive → MOTOR"]
```

Физически: f 0 → последняя Pos_Estimate из CAN Get Encoder Estimates; p 0 → CAN Simple Set Input Pos.

---

## 16. Диагностика ODrive: итоговый зафиксированный список (CAN Simple, fw v0.5.6)

Итоговое решение по CAN-диагностике, зафиксированное в спецификации (история обсуждения и обоснование — см. `ELLIC_worklog.md`, раздел «История решённых вопросов»):

**CAN (ESP32 TWAI):**

- TX = GPIO16
- RX = GPIO17
- bitrate = 250000 бит/с
- transceiver = SN65HVD230

**ODrive diagnostics (используемые CAN Simple сообщения):**

| Command ID | Сообщение |
|---|---|
| `0x01` | Heartbeat |
| `0x03` | Motor Error |
| `0x04` | Encoder Error |
| `0x09` | Encoder Estimates |
| `0x14` | Iq |
| `0x17` | Bus Voltage/Current |
| `0x1D` | Controller Error |

**Явно удалено из спецификации:** Vq (отдельного CAN Simple сообщения в v0.5.6 нет), Procedure_Result (в Heartbeat v0.5.6 отсутствует, для задачи не нужен).

Итоговый состав `OdriveSnapshot` (раздел 12.3 актуализирует более раннюю версию структуры без Vq и Procedure_Result): axisState, axisError, motorError, encoderError, controllerError, trajectoryDone, Iq (Iq_Measured), velEstimate, busVoltage, busCurrent, txCount, rxCount, rxFailCount, diagnosticsTimestampMs.

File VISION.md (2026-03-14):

# ELLIC

### Open Locomotion Platform & Future MechSport League

**Ellic** is an open research platform exploring a new class of human-scale locomotion mechanisms.

Our long-term dream is ambitious:

> Build a global **mech sport league** as exciting and profitable as Formula-style racing — powered by open robotics and human-piloted machines.

The Ellic platform is the first step.

It combines mechanical locomotion, robotics, VR interaction, and competitive gameplay into a new form of sport and engineering culture.

---

не загрузилось
---

# The Vision

Imagine a new type of championship.

Human pilots ride mechanical walking machines.

Teams design their own vehicles based on a shared open platform.

Matches happen in both **physical arenas and virtual environments**.

Fans follow teams, players, and machines just like traditional motorsport.

There are tournaments, leagues, and world cups.

Collectors trade digital artifacts, machine skins, and historical cards of legendary matches.

Sponsors support teams.

Betting platforms analyze performance.

And millions watch the evolution of a new sport.

That is the long-term vision of the **Ellic MechSport League**.

---

не загрузилось

---

# Why Open Source?

Great technological cultures grow around **open platforms**.

We believe the fastest way to build a new sport is to let the world participate.

This repository contains the foundations of the Ellic platform:

* locomotion mechanism research
* CAD models and prototypes
* control firmware
* robotics interfaces
* VR and simulation experiments
* documentation and engineering notes

Our goal is simple:

**let anyone build, improve, and compete.**

---
не загрузилось
---

# The Current Prototype

The current experimental machine is an **elliptical walking scooter mechanism**.

It is a compact human-scale locomotion device combining:

* mechanical walking kinematics
* electric drive
* robotic control systems
* interactive VR integration

The design aims to create a new category between:

* scooter
* exoskeleton
* robotic vehicle

The result is a **human-piloted locomotion platform**.

не загрузилось
---

# The Long-Term Goal

We are not just building a machine.

We are building an **ecosystem**.

Future stages include:

**1. Open Hardware Platform**

Builders around the world replicate and modify the Ellic mechanism.

**2. Experimental Competitions**

Small community tournaments begin to appear.

**3. VR Integrated Matches**

Physical locomotion interacts with digital battle environments.

**4. Team Culture**

Engineering teams design their own machines and strategies.

**5. Media Championship**

A global mech sport league emerges.

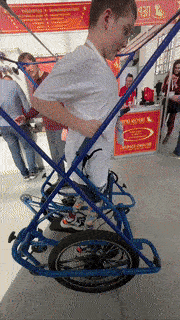
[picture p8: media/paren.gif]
не отразилось

---

# The Community

This repository is the starting point for a global builder community.

You can participate as:

* teams
* engineer
* roboticist
* designer
* game developer
* mechanical builder
* VR developer
* sponsor
* fan

Or simply someone curious about the future of robotics and sport.

---

# What We Share

This repository will gradually include:

* CAD models
* firmware
* robotics interfaces
* VR experiments
* simulation tools
* research notes
* competition ideas

The intention is to **make replication possible**.

If you want to build your own machine — the resources will be here.

---

# How To Join

There are many ways to participate.

### Builders

Try building your own Ellic machine.

### Engineers

Improve the mechanism, firmware, or control systems.

### Game Developers

Help create VR environments and competitive mechanics.

### Researchers

Explore locomotion, biomechanics, and robotics control.

### Media Creators

Document the evolution of the machines.

### Sponsors

Support early tournaments and teams.

---

# Future Competitions

The ultimate goal is to create a new kind of championship.

Possible formats include:

* mech racing
* arena duels
* VR combat tournaments
* team challenges
* endurance competitions

Each machine, team, and pilot becomes part of the sport’s evolving history.

---
# Supporting the Project

Developing hardware platforms takes time and resources.
One way to support the project is to acquire an early assembled Ellic prototype.

We are preparing a small number of fully assembled machines that teams can purchase.

Price: ≈ 1M RUB ($20k) 
Research machine founder edition 15.

Gettin one allows you to:
- Save significant engineering time
- test control immediately
- develop XR competition concepts
- bit mythology of the future sport

---
# Your support to organize comunity competitions.

If you believe in the idea of a new robotic sport:

* star the repository
* contribute ideas or code
* share the project
* support development
* build your team

Early supporters help shape the foundation of an entirely new competitive ecosystem.

---

# The Beginning

Every major sport began with a few experimental machines and a handful of enthusiasts.

Today motorsport fills stadiums.

Esports fill arenas.

Robotics will follow.

This repository is the beginning of that journey.

If you want to help build the future of mech sport:

**join us.**

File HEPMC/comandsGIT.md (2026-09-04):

# Перейти в корень репозитория
cd C:\Users\Dim\YandexDisk\ELLIC\ellic

# Получить последние изменения с GitHub
git pull origin main --rebase

# После перемещения проверить статус Git
git status
# Будут показаны удалённые файлы (из старых мест) и новые (в media)

# Добавить все изменения в индекс
git add -A

# Сделать коммит
git commit -m "Commit"

# Отправить на GitHub
git push origin main

# выводит и сохраняет в кэш все файлы репозитория с путями
git ls-files --cached --others --exclude-standard | ForEach-Object { Split-Path $_ -Parent } | Where-Object { $_ } | Sort-Object -Unique 

# Сохраняет в кэш все тексты .md
git ls-files -- '*.md' | ForEach-Object { Get-Content $_ } | Set-Clipboard

скопироать в кэш
| Set-Clipboard

посмотреть что в гитигноре
Get-Content .gitignore

# выводит даты изменений по файлу
git log --pretty=format:"%h %ar %s" --date=relative cad/fusion/PARTS/

642651a 1773822342 Change name wheels compons
bb9062f 1773822208 start to razbirat components of model fusion

# Сохранение версии файла по пути и новому имени
PS C:\Users\Dim\YandexDisk\ELLIC\ellic> git show 642651a:"cad/fusion/PARTS/WHEELS/Wheel_d24_nonMotored.f3d" >cad/fusion/PARTS/WHEELS/Wheel_d24_nonMotored_642651a.f3d

# Сохранить тексты файлов:
    Get-ChildItem -Recurse -Include *.cpp,*.h | ForEach-Object { "=== $($_.Name) ==="; Get-Content $_.FullName; "`n" } | Out-File output.txt

# .venv
cd C:\Users\Dim\YandexDisk\ELLIC\ellic
.venv\Scripts\activate

# bluetooth
cd C:\Users\Dim\YandexDisk\ELLIC\ellic\firmware\telemetry
python ble_logger.py

# odrivetool

dev0.axis0.error
dev0.axis0.motor.error
dev0.axis0.encoder.error
dev0.axis0.controller.error

dump_errors(dev0)

dev0.clear_errors()

dev0.axis0.requested_state = AXIS_STATE_IDLE

dev0.axis0.requested_state = AXIS_STATE_FULL_CALIBRATION_SEQUENCE

dev0.axis0.current_state
dev0.axis0.motor.is_calibrated
dev0.axis0.encoder.is_ready

\\\ Запуск мотора в обход чегото. дергаетя потом в одну сторону потом в другуг сторону работает
dev0.axis0.requested_state = AXIS_STATE_ENCODER_OFFSET_CALIBRATION

dev0.save_configuration()

In [113]: dev0.axis0.config.startup_encoder_offset_calibration = False

In [114]: dev0.axis0.encoder.config.pre_calibrated = True

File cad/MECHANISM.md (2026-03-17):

# ⚙️ Ellic Walking Mechanism

## 🧭 Overview

**Ellic** uses an **elliptical walking linkage** to create a human-scale locomotion system.

The mechanism converts **continuous rotary motion** into a **closed stepping trajectory**.

Instead of rolling like a wheel, the foot follows a path that **approximates a walking step**.

This creates a motion somewhere between:

- 🛴 a scooter  
- 🤖 a walking robot  
- 🦿 a mechanical exoskeleton vehicle  

# 🔁 Motion of the Mechanism 

<p align="center">
  View Ellic Model
</p>

The video above shows the **core motion principle** of the Ellic walking mechanism.

A rotating crank drives a linkage that moves the foot along an elliptical path.

---
# 🧩 Main Mechanical Elements

The basic mechanism consists of several key components:

- 🧱 **Frame** — structural base of the machine  
- ⚙️ **Main crank** — rotating element driven by the motor  
- 🔗 **Connecting rod** — transfers motion from the crank to the linkage  

Together these elements form the **elliptical walking linkage**.

---

# ⚙️ How the Mechanism Works

1️⃣ The **main crank rotates** continuously.  

2️⃣ The crank **drives the connecting rod**.  

3️⃣ The linkage constrains the motion of the foot element.  

4️⃣ The foot follows an **approximately elliptical trajectory**.

This trajectory produces a **step-like ground interaction** rather than pure rolling motion.

The result is a **stable stepping locomotion pattern** suitable for a human-scale vehicle.

---

# 📏 Typical Kinematic Parameters

The behavior of the mechanism is determined by several geometric parameters:

- ⏱ **wheels size**  
- 📐 **step length** 
- 📐 **hands width**  
 - 🔩 **link lengths**

Changing these parameters alters:

- walking smoothness  
- stability  
- propulsion efficiency  
- rider comfort  

---

# 🧪 Current Prototype

CAD models are available in multiple engineering formats:

- 🧩 **STEP** — engineering CAD exchange  
- 🧱 **STL** — mesh model for prototyping  
- 🛠 **Fusion 360 source** — full design history  

---

# 🧷 Ellic V14 Model

The **Ellic V14 CAD model** can be accessed here

👉 **[CAD]()**

These files allow engineers to:
- 🔍 explore the mechanism  
- 📊 analyze the kinematics  
- 🛠 experiment with modifications  
- 🤖 build their own prototype

<p align="center">
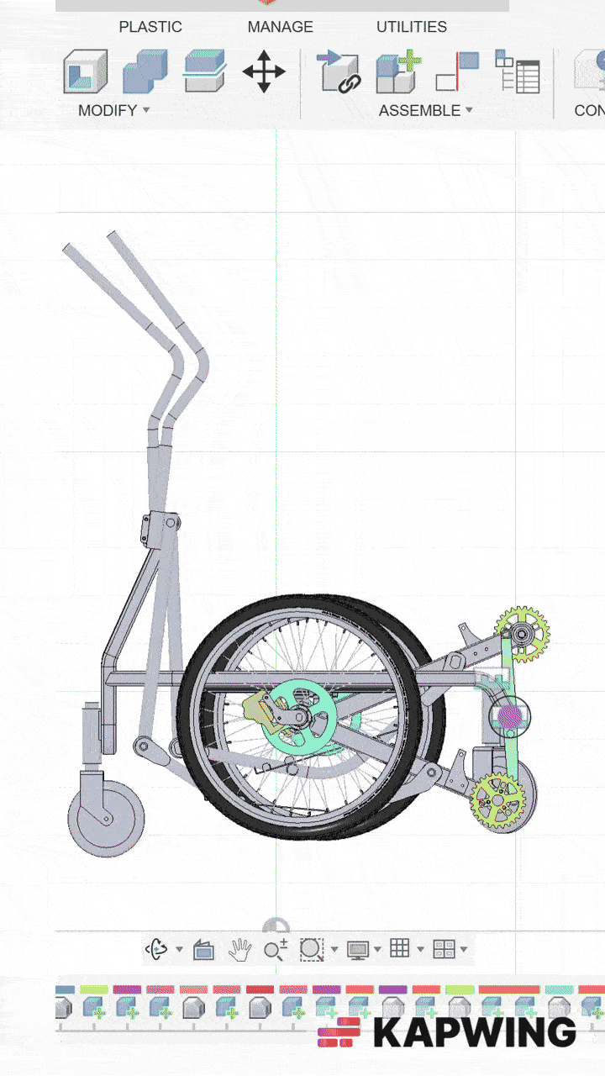
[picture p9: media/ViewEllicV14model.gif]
View Ellic Model
  
</p>

---

# 🚀 Why This Mechanism Exists

The Ellic project explores whether **human-scale walking machines** can become a new class of locomotion platform.

Possible future directions include:

- 🤖 robotics research  
- 🛴 experimental mobility systems  
- 🕶 VR-linked locomotion  
- 🏁 human-piloted mech competitions  

The mechanism is still evolving.

This repository documents the **current stage of the experiment**.

[README.ma](README.md)

[START_A_TEAM](START_A_TEAM.md)

---

<a href="https://github.com/Dvijtech/ellic/stargazers" target="_blank" style="text-decoration:none;">
  <kbd>⭐ Star the repository</kbd>
</a>

<a href="https://github.com/Dvijtech/ellic/fork" target="_blank" style="text-decoration:none;">
  <kbd>🔧 Fork the project</kbd>
</a>

<a href="https://github.com/Dvijtech/ellic/issues" target="_blank" style="text-decoration:none;">
  <kbd>💡 Open issues with ideas</kbd>
</a>

<a href="https://twitter.com/intent/tweet?text=Check+out+this+project+on+GitHub&url=https://github.com/Dvijtech/ellic" target="_blank" style="text-decoration:none;">
  <kbd>📢 Share the project</kbd>
</a>

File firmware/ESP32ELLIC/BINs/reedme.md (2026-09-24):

v2 работает на кан шине. ошибок почти нет

v1_2 Клод собрал телеметрию через блютус но очень много файлов. следующей итерацией упрощу структуру модулей.

# ELLIC — Turn Control Firmware

Прошивка ESP32, управляющая двумя колёсными приводами ODrive по сигналу с энкодера AS5600 на валу руля, с ручным доводом поворота через тормозные ручки.

## Платформа

```ini
[env:mhetesp32devkit]
platform = espressif32@6.8.1
board = mhetesp32devkit
framework = arduino

lib_deps =
    RobTillaart/AS5600
    lemmingDev/ESP32-BLE-Gamepad
```

## Идея работы

1. Датчик **AS5600** на валу читает угол поворота руля (0–360°) и превращает его в непрерывный (не обрезающийся на границе 0/360) угол.
2. Непрерывный угол переводится в целевое число оборотов колёсных моторов через передаточное число `GEAR_RATIO`.
3. Целевая позиция отправляется на оба привода **ODrive** по UART в закрытом контуре позиции (`input_pos`).
4. Левое и правое колесо крутятся в **противоположные стороны** относительно вала — это заложено в знаках при расчёте целевой позиции (моторы стоят зеркально).
5. Если водитель зажимает **тормозную ручку**, и руль находится в "зоне поворота" (около 0°/360° или 180°) — соответствующее колесо отключается от общей логики и начинает **доворачиваться вручную**, шагами `TURN_STEP`, пока тормоз зажат. Второе колесо продолжает работать штатно.
6. При отпускании тормоза накопленный доворот фиксируется как постоянное смещение (`holdOffset`) и логика возвращается к обычному режиму.
7. Отдельно отслеживается живость каждого ODrive (пропадание/восстановление питания) — при восстановлении привод переинициализируется и возвращается в закрытый контур.

## Структура файлов

```
src/
├── main.cpp              — сборка всех модулей, setup()/loop()
├── Encoder.h              — обёртка над AS5600
├── ODriveUART.h/.cpp      — общение с одним приводом ODrive по UART
├── PhaseDetector.h/.cpp   — чтение тормозных ручек, определение "зоны поворота"
├── MotionController.h/.cpp — основная логика движения и ручного доворота
├── Debug.h/.cpp           — весь вывод в Serial, отдельно от логики
└── BLETrigger.h/.cpp      — BLE-геймпад (заглушка, требует доработки)
```

### `Encoder`
Инициализирует AS5600 на заданных пинах I2C, читает угол и накапливает **непрерывный угол** (`continuousAngle`) — то есть при переходе через 0°/360° не происходит скачка. Именно это значение, умноженное на передаточное число, задаёт целевую позицию моторов.

- `begin(sda, scl)` — инициализация, проверка магнита.
- `update()` — вызывается каждый `loop()`, обновляет `rawAngle` и `continuousAngle`.
- `resetBaseline()` — сбрасывает точку отсчёта дельты угла (не сбрасывает накопленный `continuousAngle`).

### `ODriveUART`
Инкапсулирует управление одним приводом: отправку целевой позиции, переключение состояний (idle/closed loop), проверку связи (`checkAlive` — пингует `r vbus_voltage` и ждёт ответ 100 мс) и восстановление после пропадания питания (`reinit`).

Создаётся два экземпляра — `leftDrive` и `rightDrive`, на `Serial1` и `Serial2` соответственно.

### `PhaseDetector`
Читает состояние двух тормозных ручек (`INPUT_PULLDOWN`) и определяет, находится ли текущий угол вала в "зоне поворота" — там, где разрешён ручной доворот:
- около 0° / 360° (±10°)
- около 180° (±10°)

### `MotionController`
Главная логика. На каждом шаге управления (период `CONTROL_PERIOD`, по умолчанию 50 мс):

- **Оба тормоза зажаты** — оба привода в idle.
- **Зажат только левый тормоз** (в зоне поворота) — левый привод в idle, правый доворачивается вручную с шагом `TURN_STEP`.
- **Зажат только правый тормоз** (в зоне поворота) — правый привод в idle, левый доворачивается вручную с шагом `TURN_STEP` в противоположную сторону.
- **Тормоза не зажаты** — оба привода в закрытом контуре, едут по целевой позиции от энкодера + накопленное смещение доворота (`holdOffset`).

Знаки, определяющие направление вращения (подобраны экспериментально под конкретную сборку):
- Общее направление вращения обоих колёс от угла вала — знак минус перед `_encoder.continuousAngle()` при расчёте `_targetTurnsV`.
- Левое/правое колесо крутятся зеркально друг другу за счёт разных базовых знаков (`+targetTurnsV` для левого, `-targetTurnsV` для правого).
- Доворот при зажатом правом тормозе вычитается (`-= _turnStep`), при зажатом левом — прибавляется (`+= _turnStep`), чтобы левое и правое колесо доворачивались в противоположные стороны.

### `Debug`
Весь `Serial.print`/`println` вынесен сюда, чтобы не засорять логику. Периодически (`PRINT_PERIOD`, по умолчанию 100 мс) выводит строку состояния:

```
RAW:<угол вала> TARGET:<целевые обороты> LB:<левый тормоз> RB:<правый тормоз> Z:<в зоне поворота?> LO:<смещение слева> RO:<смещение справа>
```

Плюс отдельные методы для логов инициализации/переподключения ODrive.

### `BLETrigger` — требует доработки
Пустой на момент рефакторинга. В `main.cpp` вызывается `BLETrigger_begin()` и `BLETrigger_update()`, но их реальное содержимое нужно написать — сейчас там временная заглушка на базе `ESP32-BLE-Gamepad`.

## Настройки (`main.cpp`)

| Константа | Значение | Смысл |
|---|---|---|
| `GEAR_RATIO` | 4.4 | Передаточное число вал → колесо |
| `TURN_STEP` | 0.03 | Шаг доворота колеса за одну итерацию управления при зажатом тормозе |
| `CONTROL_PERIOD` | 50 мс | Период пересчёта и отправки целевой позиции на приводы |
| `PRINT_PERIOD` | 100 мс | Период отладочного вывода в Serial |
| `ODRIVE_CHECK_PERIOD` | 1000 мс | Период проверки связи с ODrive |
| `ODRIVE_BOOT_DELAY` | 1500 мс | Задержка перед переинициализацией привода после восстановления питания |

## Пины

| Назначение | Пин |
|---|---|
| I2C SDA (AS5600) | 21 |
| I2C SCL (AS5600) | 22 |
| ODrive Left RX / TX | 16 / 17 |
| ODrive Right RX / TX | 26 / 25 |
| Тормоз левый | 32 |
| Тормоз правый | 33 |

## Известные ограничения / TODO

- `BLETrigger` — заглушка, нужно вписать реальную логику геймпада.
- Знаки направления вращения подобраны под конкретную механическую сборку — при смене редуктора/моторов их придётся перепроверить.

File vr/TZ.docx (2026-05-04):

# 📄 ТЗ: MVP боя мехов (Blueprint-only, XR + Screen + Server)

# 🎯 ЦЕЛЬ

Собрать сетевой VR-прототип, где:

- прицел и цель считаются в экранном пространстве
- попадание считается на сервере
- есть видеопоток от лица игроков
- архитектура позволяет заменить AI на реального игрока без переделки

# 🧱 АРХИТЕКТУРА

Разделение:

1. Player (ввод, камера)
2. Aiming (прицел)
3. TargetProvider (источник цели)
4. Combat (попадание)
5. Networking (RPC, репликация)
6. Video (SceneCapture)

# 📦 СПИСОК BLUEPRINT

## Player

- BP_VRPlayerPawn
- BP_PlayerController
- BP_PlayerState

## Gameplay

- BP_AimingComponent
- BP_CombatComponent
- BP_TargetProvider_Base
- BP_TargetProvider_AI
- BP_TargetActor_AI

## Networking

- BP_GameMode
- BP_GameState

## Video

- BP_VideoCaptureComponent
- BP_VideoScreenActor

# 🎮 PLAYER

## BP_VRPlayerPawn

### Компоненты:

- Camera (VR Camera)
- MotionController (L/R)
- BP_AimingComponent
- BP_CombatComponent
- BP_VideoCaptureComponent

### Переменные:

- PlayerID
- bIsLocalPlayer

### BeginPlay:

if IsLocallyControlled:

bIsLocalPlayer = true

## BP_PlayerController

### Функции:

FireInput()

### Логика:

OnTriggerPressed →

Pawn.CombatComponent → RequestFire()

## BP_PlayerState

### Переменные (Replicated):

- HP
- PlayerName

# 🎯 AIMING

## BP_AimingComponent

### Переменные:

- AimScreenPos (Vector2D)
- ScreenCenter
- UseControllerOffset (bool)
- AimOffsetScale = 400
- MaxOffsetClamp = 300

## Tick (Client)

### 1. Центр экрана

GetViewportSize → /2 → ScreenCenter

### 2. Базовый прицел

AimScreenPos = ScreenCenter

### 3. Offset (если включен)

Get Camera Forward

Get Controller Forward

DeltaRot = ControllerRot - CameraRot

OffsetX = Yaw * Scale

OffsetY = Pitch * Scale * -1

Clamp → MaxOffsetClamp

AimScreenPos += Offset

# 🎯 TARGET

## BP_TargetProvider_Base

### Функции:

GetTargetScreenPosition(PlayerController)

IsTargetVisible()

GetTargetActor()

## BP_TargetProvider_AI

### Переменные:

- TargetActor (BP_TargetActor_AI)

### Логика (Server):

GetActorLocation(TargetActor)

ProjectWorldToScreen(PlayerController)

return Vector2D

## BP_TargetActor_AI

### Компоненты:

- StaticMesh

### Переменные:

- HP (Replicated)

### Движение:

Tick:

X += sin(time) * speed

# 💥 COMBAT

## BP_CombatComponent

### Переменные:

- AimRadius = 120
- LockTime = 0.3
- LockProgress
- TargetProvider

## ФУНКЦИИ

### RequestFire (Client)

Get AimScreenPos

Call Server_Fire(AimScreenPos)

### Server_Fire (Run on Server)

Validate AimScreenPos

TargetPos = TargetProvider.GetTargetScreenPosition(PlayerController)

Distance = |Aim - Target|

if Distance < AimRadius:

ApplyDamage

### ApplyDamage

TargetActor.HP -= Damage

if HP <= 0:

Destroy / Respawn

# 🌐 NETWORKING

## BP_GameMode (Server)

### BeginPlay:

Spawn AI Target

Assign TargetProvider

## BP_GameState (Replicated)

### Переменные:

- Players Array
- MatchState

# 📡 VIDEO SYSTEM

## BP_VideoCaptureComponent

### Компоненты:

- SceneCaptureComponent2D
- TextureRenderTarget2D

### Настройки:

- Capture Source: Final Color
- Resolution: 512–1024

### BeginPlay:

Attach SceneCapture to Camera

Assign RenderTarget

## BP_VideoScreenActor

### Компоненты:

- Plane Mesh

### Материал:

Texture = RenderTarget

## ЛОГИКА

Каждый игрок:

имеет свой RenderTarget

Экран:

показывает нужного игрока

# 🖥️ UI

Создать Widget:

- Crosshair (центр)
- Target dot
- Lock indicator
- HP bar

# 🧪 DEBUG

Выводить:

AimScreenPos

TargetScreenPos

Distance

Ping

# ⚙️ PICO ОПТИМИЗАЦИЯ

- не более 1 SceneCapture на игрока
- ограничить FPS
- простой UI

# 🚀 ПОРЯДОК СБОРКИ

## Этап 1

Player + Camera

## Этап 2

Aiming (центр)

## Этап 3

AI Target

## Этап 4

Combat (локально)

## Этап 5

Server RPC

## Этап 6

Video Capture

## Этап 7

Offset

# 🔜 РАСШИРЕНИЕ

Без переделки:

AI → Player TargetProvider

# ❌ НЕ ДЕЛАТЬ

- OpenCV
- QR
- сложную физику
- peer-to-peer

# 💡 КРИТЕРИЙ УСПЕХА

- игрок понимает стрельбу
- попадания предсказуемы
- работает в сети
- видео отображается
- AI легко заменяется игроком

# 🧠 СУТЬ

👉 Всё в экранном пространстве
👉 Сервер решает попадание
👉 Источник цели заменяемый

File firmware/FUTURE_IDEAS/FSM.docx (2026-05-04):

# ⚙️ ФУНКЦИОНАЛЬНАЯ СХЕМА УПРАВЛЕНИЯ (ELLIC / шагающая платформа)

## 1. ВХОДЫ (SENSORS / INPUT LAYER)

### 🔵 Датчики состояния системы

- Энкодер коленвала → фаза шага (положение в цикле движения)
- IMU (гироскоп / акселерометр) → угол наклона (pitch/roll) → угловая скорость (динамика устойчивости)
- Датчики тока моторов → нагрузка / сопротивление → косвенно: контакт с поверхностью / перегрузка

### 🔵 Органы управления пользователя

- Тормозные ручки → торможение / поворот (дифференциальное управление)
- Датчики момента на рычагах → усилие пользователя при старте / разгрузка / ассист
- Джойстик → целевое движение (направление / интенсивность)

### 🔵 Системные / интерфейсные сигналы

- Сигнал эмуляции клавиатуры → управляющие команды / режимы (start / mode / debug)
- Дисплей (состояние системы) → режимы работы → телеметрия в реальном времени
- Логирование поездки → запись параметров движения и состояния системы
- Передача данных (Bluetooth → ПК) → телеметрия / анализ / отладка

## 2. ПРЕДОБРАБОТКА СИГНАЛОВ (NORMALIZATION LAYER)

Здесь ты приводишь всё к “физическому смыслу управления”:

- Энкодер → фаза шага (0–360°)
- IMU → угол + угловая скорость
- Ток → нагрузка / сопротивление
- Датчики момента → усилие пользователя (intent start / assist)
- Тормоза → команда поворота / остановки
- Джойстик → целевой вектор движения
- Клавиатура → дискретные режимы управления
- Лог / дисплей / BT → наблюдение и обратная связь (НЕ управление)

## ⚠️ ВАЖНОЕ УПРОЩЕНИЕ (которое тебе сильно поможет)

Вот что ты сейчас неявно сделал правильно, но его надо зафиксировать:

### Разделение систем:

#### 1) CONTROL INPUT (реальное управление)

- IMU
- энкодер
- ток
- датчики момента
- ручки / джойстик

#### 2) CONTROL OUTPUT / UX LAYER (не управление, а наблюдение)

- дисплей
- лог
- bluetooth
- клавиатура

## 💡 КЛЮЧЕВАЯ МЫСЛЬ, КОТОРУЮ ТЫ ДОЛЖЕН ЕМУ ПЕРЕДАТЬ

Если очень коротко:

👉 “управление системой = сенсоры + физика движения”
👉 “всё остальное = интерфейс и диагностика”

Дальit старое:

## 3. ОСНОВНЫЕ КОНТУРЫ УПРАВЛЕНИЯ (CONTROL LAYERS)

### 🟡 A. КОНТУР СТАБИЛИЗАЦИИ (главный)

- вход: IMU (наклон)
- цель: удержание равновесия
- выход: корректировка тяги моторов

👉 самый быстрый и критичный контур

### 🟡 B. КОНТУР ШАГА (GAIT / PHASE CONTROL)

- вход: энкодер (фаза коленвала)
- логика:
  - определение стадии шага
  - синхронизация усилия с фазой
- выход:
  - распределение тяги по циклу движения

### 🟡 C. КОНТУР ДВИЖЕНИЯ (USER INTENT)

- вход: джойстик
- логика:
  - направление + скорость
- выход:
  - целевой вектор движения

### 🟡 D. КОНТУР ПОВОРОТА

- вход: тормозные ручки
- логика:
  - дифференциальное управление колесами
- выход:
  - разная тяга левого/правого мотора

## 4. ФУЗИЯ УПРАВЛЕНИЯ (CONTROL ARBITRATION LAYER)

👉 самый важный блок

Он решает:

- что сейчас важнее:
  - стабилизация (всегда приоритет №1)
  - шаг
  - движение пользователя
  - поворот

### Логика приоритета:

1. СТАБИЛИЗАЦИЯ (IMU override)
2. БАЛАНС В ШАГЕ (энкодер)
3. НАМЕРЕНИЕ ПОЛЬЗОВАТЕЛЯ
4. ПОВОРОТ / КОРРЕКЦИЯ

## 5. ВЫХОД (ACTUATION LAYER)

- левый мотор
- правый мотор

Параметры:

- torque / PWM / current control
- дифференциальное управление

## 🔁 ЗАМКНУТЫЕ КОНТУРЫ (ВАЖНО ОТМЕТИТЬ СТРЕЛКАМИ)

- IMU → стабилизация → моторы → IMU
- энкодер → фаза → моторы → энкодер
- ток → защита → ограничение тяги → моторы → ток

# 🧠 КАК ЭТО ДОЛЖНО ВЫГЛЯДЕТЬ В РИСУНКЕ

Слева направо:

[SENSORS]
↓
[PREPROCESSING]
↓
[CONTROL LAYERS]
↓
[ARBITRATION]
↓
[ACTUATORS]
↓
(обратные связи назад в SENSORS)

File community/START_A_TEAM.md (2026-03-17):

# 🚀 Start an Ellic Team

To participate in the first **mech sport experiments** you need a small team.

## 👥 Minimum team structure

1. **🔧 Fabrication Engineer**  
   Responsible for mechanical assembly, repair and mechanical modifications.  

2. **🧠 XR Engineer**  
   Responsible for control systems, firmware and VR interaction.  

3. **🎥 Media Producer**  
   Responsible for filming, editing and publishing team content.  

Teams can be as small as **2–3 people**.  
One person may combine several roles.

# 🌍 Who Might Start an Ellic Team

Different kinds of builders and operators may see themselves in this project.

## 🏎 Karting Track Owners

If you run a karting track or motorsport facility, you already have most of the infrastructure needed for mech sport.

You likely already have:

- mechanical workshops  
- mechanics and technicians  
- competitive drivers  
- a racing culture  

---

## 🥽 VR Arena Owners

- a new attraction for visitors  
- a competition format for young players  
- a basis for educational programs combining engineering and gameplay

---

## 📺 Tech YouTubers and Streamers

If you are a **tech YouTuber, maker, or streamer**, Ellic can become a powerful content project.

The platform combines:

- XR gameplay  
- robotics  
- bionic locomotion machines  
- experimental sport  

Building and piloting an Ellic machine is both a **technical challenge** and a **content story**.

Streamers and creators can build their own teams and document the process for their audiences.

---

## 🎨 Designers and Visual Creators

Experimental machines become much more powerful when they have strong visual identity.

Teams may include:

- industrial designers  
- concept artists  
- 3D artists  
- visual creators  

Designers can develop:

- machine body kits  
- visual concepts for mech sport machines

These visual elements help transform machines into **recognizable competitors and media characters**.

---

## 🛠 Individual Pro

Want to participate but don’t yet have a team?

You can register yourself to **find teammates** for a new project.

📧 Write to: **dselog@gmail.com**

Use the subject: find teammates
**Nickname:**  
**Skill:** (Fabrication / VR / Media)  
**Interested in:** (Mech Sport League / Para Mech Sport)

# 🏁 CORE TEAMS

Early teams will become the **core teams of the first mech sport league**.

The long-term vision is similar to modern motorsport leagues such as **Formula 1 racing**, where teams compete with their own machines while participating in a shared media and competition ecosystem.

## 💰 League Economics (Concept)

The long-term economic model of the league is to share revenue with core teams:

* 🎬 media content and distribution  
* 🎮 live events  
* 🤝 brands & integrations  

to support the growth of both the teams and the championship ecosystem.

# 📧 Write to: **dselog@gmail.com**

[README.MD](README.md)

---

<a href="https://github.com/Dvijtech/ellic/stargazers" target="_blank" style="text-decoration:none;">
  <kbd>⭐ Star the repository</kbd>
</a>

<a href="https://github.com/Dvijtech/ellic/fork" target="_blank" style="text-decoration:none;">
  <kbd>🔧 Fork the project</kbd>
</a>

<a href="https://github.com/Dvijtech/ellic/issues" target="_blank" style="text-decoration:none;">
  <kbd>💡 Open issues with ideas</kbd>
</a>

<a href="https://twitter.com/intent/tweet?text=Check+out+this+project+on+GitHub&url=https://github.com/Dvijtech/ellic" target="_blank" style="text-decoration:none;">
  <kbd>📢 Share the project</kbd>
</a>

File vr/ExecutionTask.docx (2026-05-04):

# 🚀 EXECUTION-ТЗ ДЛЯ ЛУКИ (Blueprint-only, VR, Pico 4)

## 🧠 ПРАВИЛА РАБОТЫ

- Делай по одной задаче
- После каждой — видео/демо
- Не улучшай и не усложняй
- Если не получается → сразу пишешь

# 🟢 ЭТАП 1 — СТРЕЛЬБА ВООБЩЕ СУЩЕСТВУЕТ

## 🔹 ЗАДАЧА 1 — прицел в центре экрана

Сделай:

- UI или debug точку в центре экрана

ГОТОВО, ЕСЛИ:

- точка всегда в центре
- при повороте головы не уезжает

## 🔹 ЗАДАЧА 2 — простая цель

Сделай:

- актор с кубом перед игроком

ГОТОВО, ЕСЛИ:

- куб виден в VR
- не исчезает

## 🔹 ЗАДАЧА 3 — проекция цели на экран

Сделай:

- ProjectWorldToScreen
- получи позицию цели на экране

ГОТОВО, ЕСЛИ:

- при движении головы координаты меняются
- выводятся на экран (debug)

## 🔹 ЗАДАЧА 4 — дистанция до цели

Сделай:

- distance между центром экрана и целью

ГОТОВО, ЕСЛИ:

- значение меняется при наведении
- видно в debug

## 🔹 ЗАДАЧА 5 — попадание

Сделай:

- если distance < радиуса → hit

ГОТОВО, ЕСЛИ:

- при наведении появляется сообщение “HIT”
- при уводе — исчезает

## 🔹 ЗАДАЧА 6 — стрельба кнопкой

Сделай:

- триггер → проверка hit → print “FIRE HIT”

ГОТОВО, ЕСЛИ:

- нажал → при наведении есть попадание
- вне цели — нет

# 🟡 ЭТАП 2 — ДЕЛАЕМ ЭТО ИГРОЙ

## 🔹 ЗАДАЧА 7 — HP у цели

Сделай:

- переменную HP = 100
- при попадании уменьшается

ГОТОВО, ЕСЛИ:

- HP уменьшается
- выводится на экран

## 🔹 ЗАДАЧА 8 — уничтожение цели

Сделай:

- если HP <= 0 → уничтожить или скрыть

ГОТОВО, ЕСЛИ:

- цель исчезает после попаданий

## 🔹 ЗАДАЧА 9 — движение цели

Сделай:

- простое движение (влево/вправо)

ГОТОВО, ЕСЛИ:

- цель двигается
- по ней всё ещё можно попасть

## 🔹 ЗАДАЧА 10 — визуальный прицел

Сделай:

- нормальный crosshair (не debug)

ГОТОВО, ЕСЛИ:

- прицел видно
- он не лагает

# 🔵 ЭТАП 3 — ДОБАВЛЯЕМ СЕРВЕР

## 🔹 ЗАДАЧА 11 — запуск 2 игроков

Сделай:

- Play → 2 клиента

ГОТОВО, ЕСЛИ:

- два игрока видят сцену

## 🔹 ЗАДАЧА 12 — стрельба через сервер

Сделай:

- кнопка → Run on Server

ГОТОВО, ЕСЛИ:

- print происходит на сервере

## 🔹 ЗАДАЧА 13 — сервер считает попадание

Сделай:

- перенести проверку distance на сервер

ГОТОВО, ЕСЛИ:

- hit считается только сервером
- клиент не может «обмануть»

## 🔹 ЗАДАЧА 14 — HP синхронизируется

Сделай:

- HP replicated

ГОТОВО, ЕСЛИ:

- оба игрока видят одинаковый HP

# 🟣 ЭТАП 4 — ВИДЕО ОТ ИГРОКА

## 🔹 ЗАДАЧА 15 — SceneCapture

Сделай:

- SceneCaptureComponent2D на камере

ГОТОВО, ЕСЛИ:

- есть RenderTarget

## 🔹 ЗАДАЧА 16 — экран с видео

Сделай:

- плоскость с материалом
- вывести RenderTarget

ГОТОВО, ЕСЛИ:

- видно «вид от игрока» на экране

## 🔹 ЗАДАЧА 17 — второй игрок как источник

Сделай:

- показывать не себя, а другого игрока

ГОТОВО, ЕСЛИ:

- видишь POV другого игрока

# 🟠 ЭТАП 5 — УПРАВЛЕНИЕ ПРИЦЕЛОМ

## 🔹 ЗАДАЧА 18 — offset от контроллера

Сделай:

- смещение прицела от контроллера

ГОТОВО, ЕСЛИ:

- при движении контроллера прицел смещается

## 🔹 ЗАДАЧА 19 — clamp

Сделай:

- ограничение смещения

ГОТОВО, ЕСЛИ:

- прицел не улетает за экран

# 🔴 ЗАПРЕЩЕНО

- не использовать OpenCV
- не делать QR
- не усложнять логику
- не переписывать архитектуру

# 🧠 ЕСЛИ ЗАСТРЯЛ

Сразу написать:

- что сделал
- где не работает
- что ожидал

# 💡 ФИНАЛ

ГОТОВО, ЕСЛИ:

- можно стрелять
- есть попадания
- работает 2 игрока
- есть видео от игроков
- всё стабильно

# 💬 КАК ТЕБЕ ЭТИМ ПОЛЬЗОВАТЬСЯ

Очень просто:

- не скидывай всё сразу
- давай 2–3 задачи максимум
- требуй видео после каждой

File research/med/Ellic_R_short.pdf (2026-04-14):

# ELLIC-R

# ДОСТУПНЫЙ МОБИЛЬНЫЙ ЭКЗОСКЕЛЕТ-ВЕРТИКАЛИЗАТОР С ФУНКЦИЕЙ ХОДЬБЫ ДЛЯ РЕАБИЛИТАЦИИ

## - ЧТО ЭТО:

## Электромеханическое мобильное устройство для

восстановления ходьбы и координации.

## - ДЛЯ КОГО:

## Пациенты с ограничениями подвижности, с детским церебральным параличом (далее «ДЦП»), после

инсульта, травм.

## - ВАЖНЫЕ ОСОБЕННОСТИ:

## - полноценные перекрестные

движения рук и ног;
- адаптивная регулировка усилий электромоторами.

## ДОСТУПНАЯ ЦЕНА:

## от 400 тыс. руб. для всех, а не только для избранных клиник, что в 10 раз дешевле современных экзоскелетов при сопоставимых

характеристиках.

1

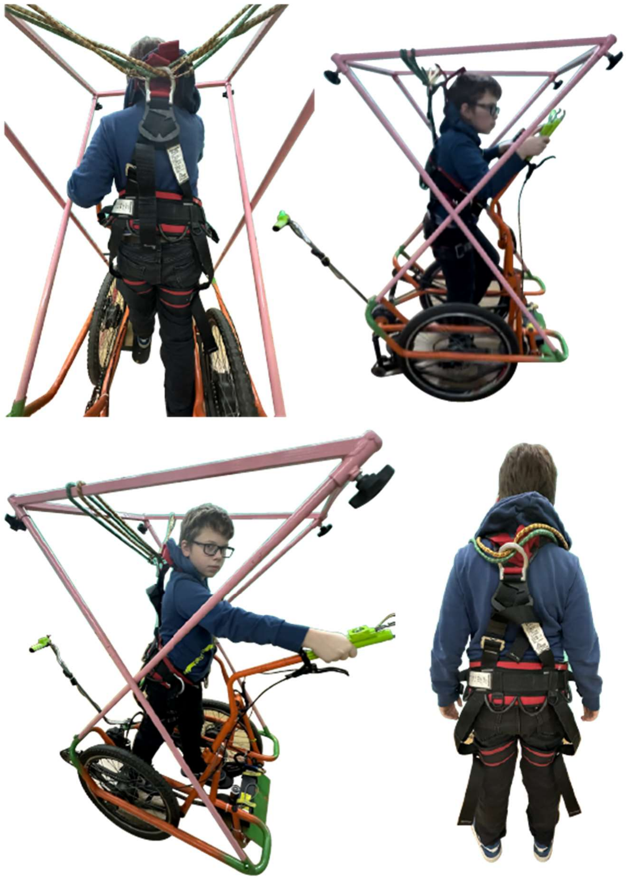
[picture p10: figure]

2

# Внешний вид прототипа ELLIC-R

# ТЕКУЩИЕ РЕШЕНИЯ НА РЫНКЕ

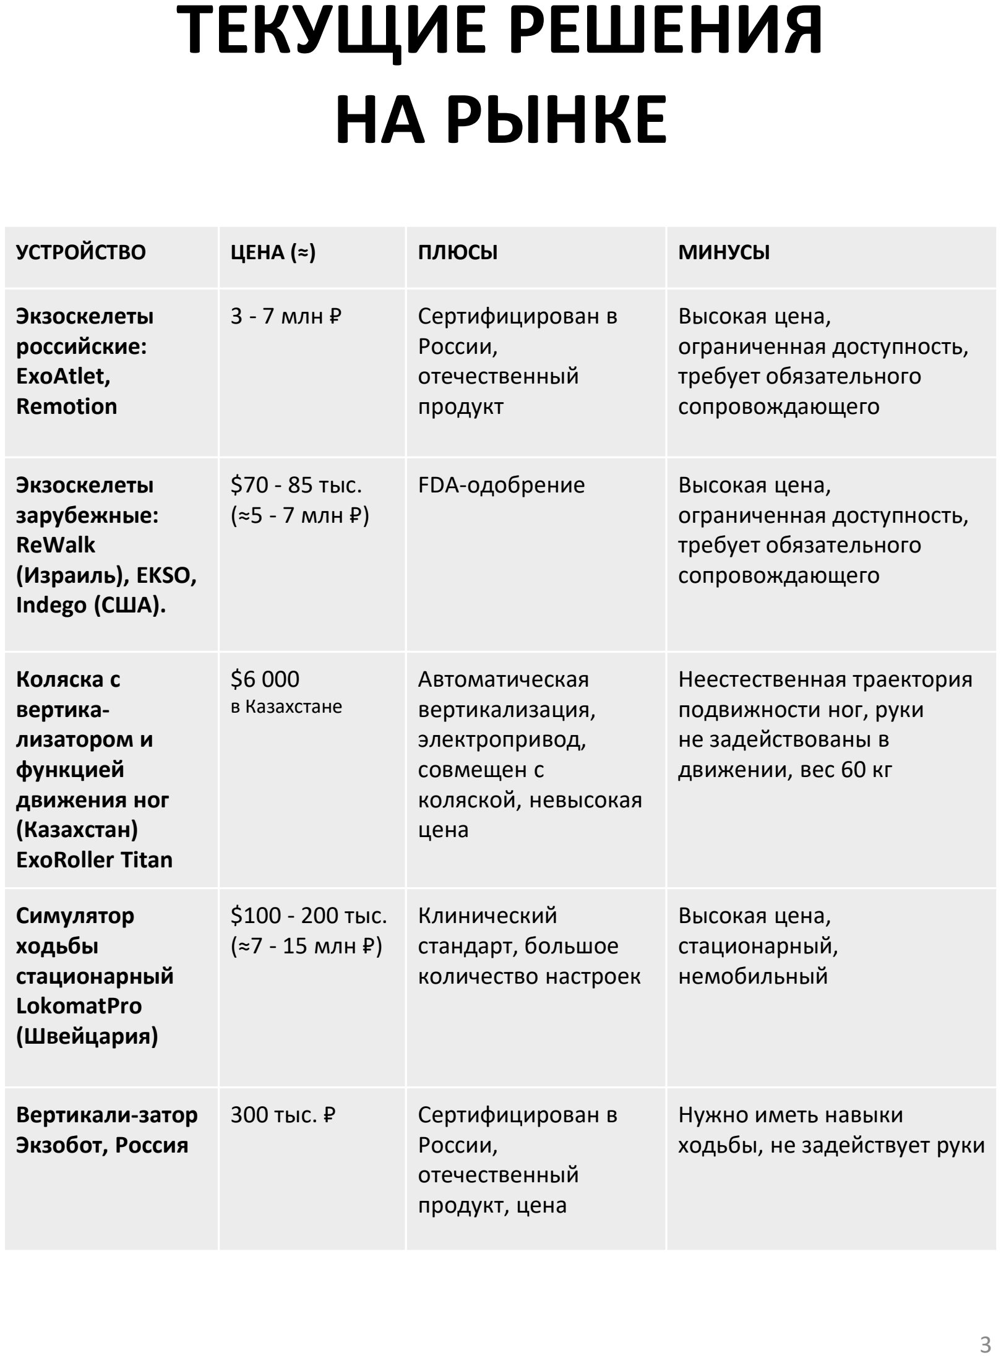
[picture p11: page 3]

УСТРОЙСТВО | ЦЕНА (≈) | ПЛЮСЫ | МИНУСЫ
Экзоскелеты российские: ExoAtlet, Remotion | 3 - 7 млн ₽ | Сертифицирован в России, отечественный продукт | Высокая цена, ограниченная доступность, требует обязательного сопровождающего
Экзоскелеты зарубежные: ReWalk (Израиль), EKSO, Indego (США). | $70 - 85 тыс. (≈5 - 7 млн ₽) | FDA-одобрение | Высокая цена, ограниченная доступность, требует обязательного сопровождающего
Коляска с вертика-лизатором и функцией движения ног (Казахстан) ExoRoller Titan | $6 000 в Казахстане | Автоматическая вертикализация, электропривод, совмещен с коляской, невысокая цена | Неестественная траектория подвижности ног, руки не задействованы в движении, вес 60 кг
Симулятор ходьбы стационарный LokomatPro (Швейцария) | $100 - 200 тыс. (≈7 - 15 млн ₽) | Клинический стандарт, большое количество настроек | Высокая цена, стационарный, немобильный
Вертикали-затор Экзобот, Россия | 300 тыс. ₽ | Сертифицирован в России, отечественный продукт, цена | Нужно иметь навыки ходьбы, не задействует руки

3

# ПРЕИМУЩЕСТВА НАШЕГО РЕШЕНИЯ

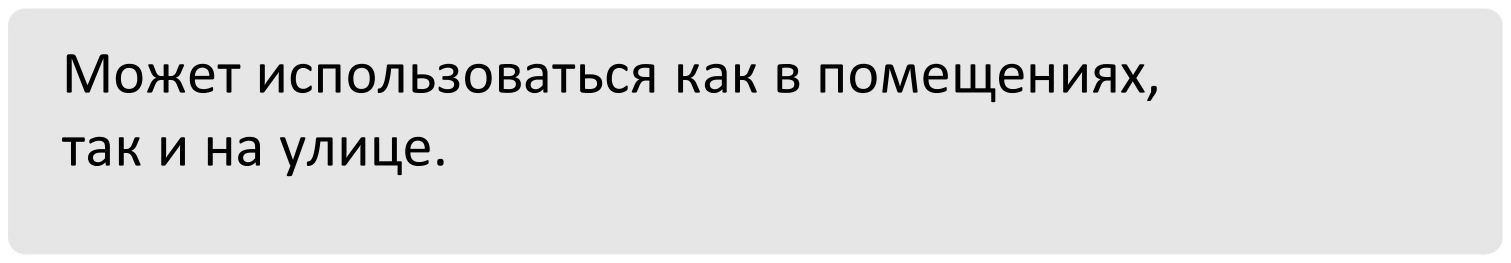
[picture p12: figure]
Может использоваться как в помещениях, так и на улице.
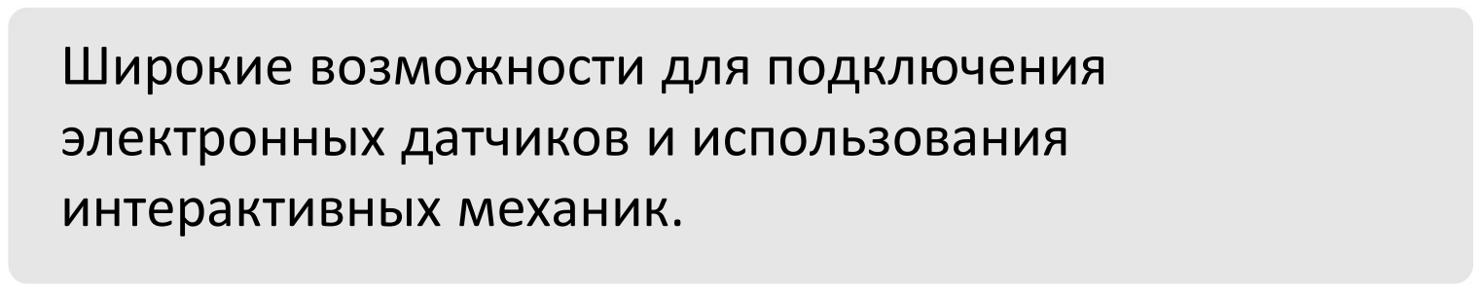
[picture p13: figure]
Широкие возможности для подключения электронных датчиков и использования интерактивных механик.
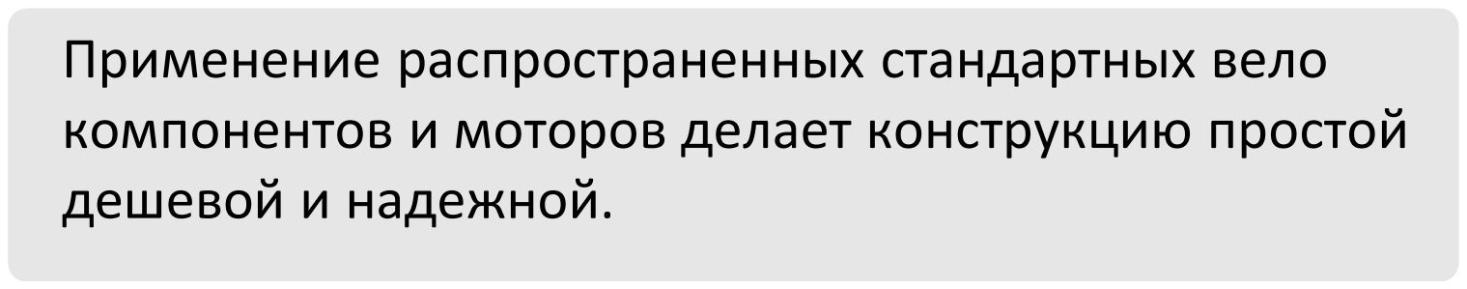
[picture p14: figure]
дешевой и надежной.

## Применение распространенных стандартных вело компонентов и моторов делает конструкцию простой

## ФУНКЦИОНАЛ СОПОСТАВИМ С ПЕРЕДОВЫМИ РЕАБИЛИТАЦИОННЫМИ ЭКЗОСКЕЛЕТАМИ И ИМИТАТОРАМИ ХОДЬБЫ ПРИ ЦЕНЕ В 10 РАЗ НИЖЕ

## ПРИ ЦЕНЕ ОБЫЧНОГО ВЕРТИКАЛИЗАТОРА РЕАЛИЗОВАНА ФУНКЦИОНАЛЬНАЯ ПОДВИЖНОСТЬ ПАЦИЕНТА

4

# СТРУКТУРА РЫНКА ОБОРУДОВАНИЯ ДЛЯ

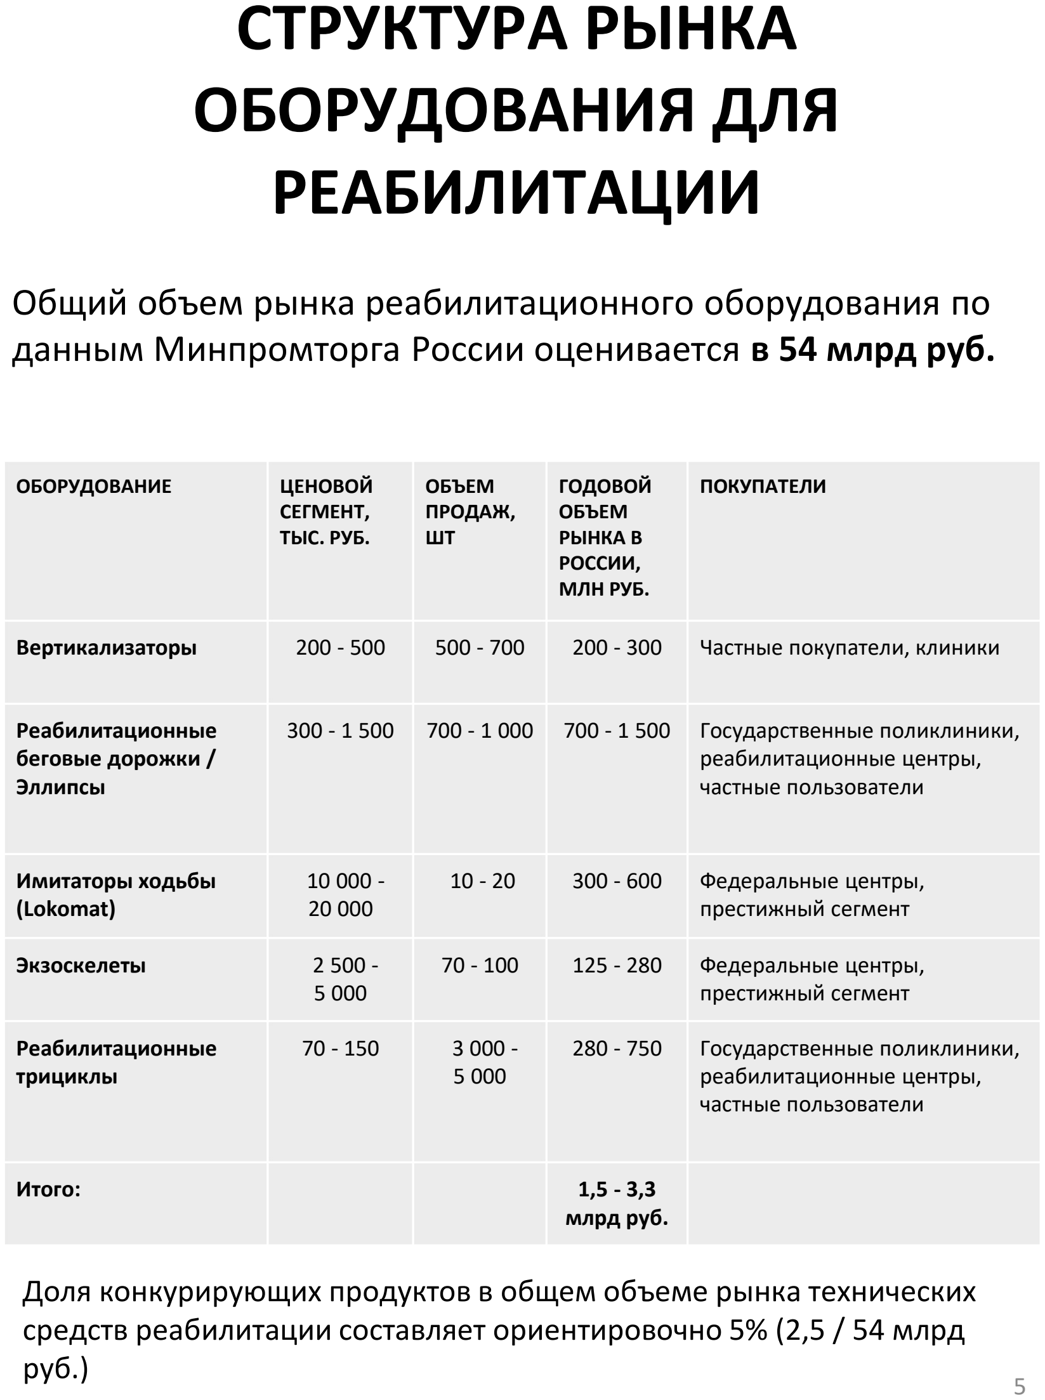
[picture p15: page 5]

# РЕАБИЛИТАЦИИ

ОБОРУДОВАНИЕ | ЦЕНОВОЙ СЕГМЕНТ, ТЫС. РУБ. | ОБЪЕМ ПРОДАЖ, ШТ | ГОДОВОЙ ОБЪЕМ РЫНКА В РОССИИ, МЛН РУБ. | ПОКУПАТЕЛИ
Вертикализаторы | 200 - 500 | 500 - 700 | 200 - 300 | Частные покупатели, клиники
Реабилитационные беговые дорожки / Эллипсы | 300 - 1 500 | 700 - 1 000 | 700 - 1 500 | Государственные поликлиники, реабилитационные центры, частные пользователи
Имитаторы ходьбы (Lokomat) | 10 000 -20 000 | 10 - 20 | 300 - 600 | Федеральные центры, престижный сегмент
Экзоскелеты | 2 500 -5 000 | 70 - 100 | 125 - 280 | Федеральные центры, престижный сегмент
Реабилитационные трициклы | 70 - 150 | 3 000 -5 000 | 280 - 750 | Государственные поликлиники, реабилитационные центры, частные пользователи
Итого: | | | 1,5 - 3,3 млрд руб.

## Общий объем рынка реабилитационного оборудования по

данным Минпромторга России оценивается в 54 млрд руб.

### Доля конкурирующих продуктов в общем объеме рынка технических средств реабилитации составляет ориентировочно 5% (2,5 / 54 млрд

руб.) | 5

# ПРОГНОЗНАЯ СТРУКТУРА РЫНКА ОБОРУДОВАНИЯ ДЛЯ

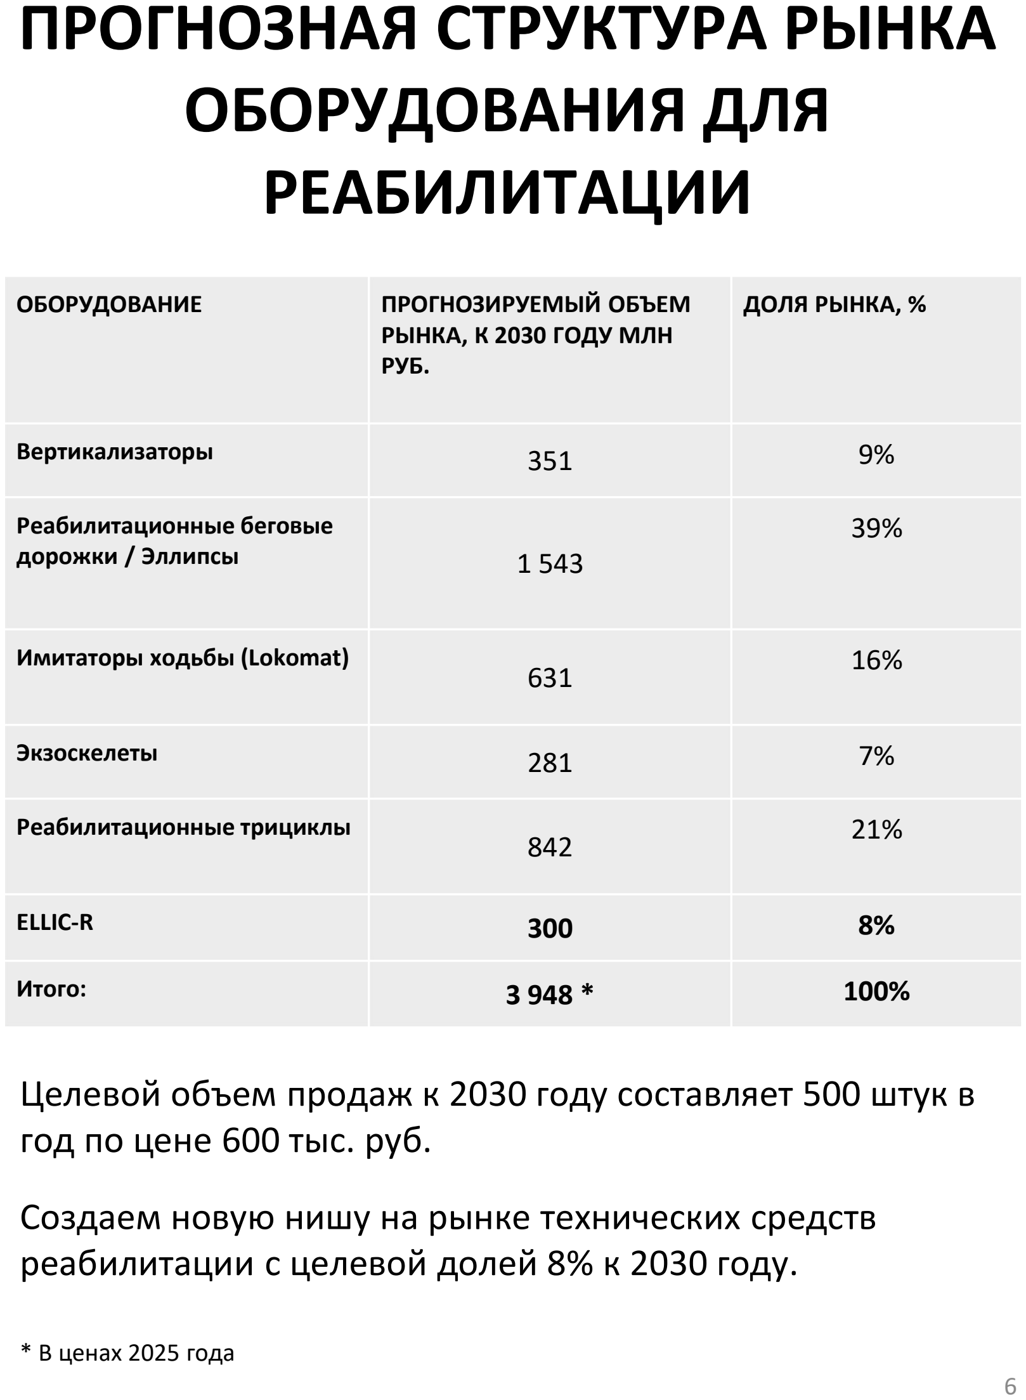
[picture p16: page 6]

# РЕАБИЛИТАЦИИ

ОБОРУДОВАНИЕ | ПРОГНОЗИРУЕМЫЙ ОБЪЕМ РЫНКА, К 2030 ГОДУ МЛН РУБ. | ДОЛЯ РЫНКА, %
Вертикализаторы | 351 | 9%
Реабилитационные беговые дорожки / Эллипсы | 1 543 | 39%
| | 16% 631 Имитаторы ходьбы (Lokomat)
Экзоскелеты | 281 | 7%
| | 21% 842 Реабилитационные трициклы
ELLIC-R | 300 | 8%
Итого: | 3 948 * | 100%

## Целевой объем продаж к 2030 году составляет 500 штук в

год по цене 600 тыс. руб.

## Создаем новую нишу на рынке технических средств

реабилитации с целевой долей 8% к 2030 году.

* В ценах 2025 года
6

# МЫ НЕ ДЕЛИМ СУЩЕСТВУЮЩИЙ РЫНОК — МЫ СОЗДАЕМ НОВЫЙ

### СУЩЕСТВУЮЩИХ РЫНОК СОСТОИТ ИЗ ДВУХ СЕГМЕНТОВ: Нишевый рынок экзоскелетов и имитаторов ходьбы, недоступных

по цене массовому потребителю,

### и широкий рынок вертикализаторов, доступных по цене, но

имеющих ограниченный функционал.

### Наша целевая аудитория: сотни тысяч пациентов (инсульт - 400 тыс. случаев ежегодно, ДЦП – 120 тыс. человек, травмы) и тысячи

региональных клиник.
Потенциальная емкость рынка: тысячи устройств в год.

### ТЕКУЩИЙ ОБЪЕМ РЫНКА: ~ 1,5 млрд руб. / год ~ 2000 аппаратов /

год.
ELLIC-R создает новый массовый рынок активной реабилитации.

### Мы делаем доступной элитарную технологию

для массового потребителя.

### НАША ЦЕНА: от 400 тыс. руб. (в 10 раз дешевле близких аналогов и более высокий класс реабилитации по сравнению с простыми

вертикализаторами).

### КЛЮЧЕВОЕ ПРЕИМУЩЕСТВО: Активная реабилитация с

вовлечением всех конечностей и геймификацией,
а не просто «ведение» пациента.

7

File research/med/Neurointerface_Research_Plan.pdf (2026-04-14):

Исследование интеграции недорогого нейроинтерфейса в модульную систему управления реабилитационной роботизированной платформой Эллик

### 1. Описание

Разработка и апробация низкобюджетной модульной архитектуры управления мобильным экзоскелетом Эллик с использованием нейроинтерфейса как одного из каналов биологической обратной связи.

### 2. Проблема

Современные системы нейроуправляемой реабилитации характеризуются высокой стоимостью, сложностью аппаратной части и недоступностью для ранних этапов реабилитации и образовательных целей. В то же время остаётся недостаточно исследованным вопрос применения нейроинтерфейсов низкой стоимости для управления реабилитационными роботизированными платформами в демонстрационных и обучающих сценариях.

### 3. Цель исследования

Оценить принципиальную возможность интеграции недорогого нейроинтерфейса в систему управления мобильным экзоскелетом для формирования канала биологической обратной связи в демонстрационных и учебных сценариях.

### 4. Гипотезы

- Использование нейроинтерфейса позволяет сформировать устойчивый канал передачи ограниченного числа управляющих команд (2–4) в систему управления мобильным экзоскелетом при условии ограничения скорости и степеней свободы движения.
- Пользователь способен обучаться управлению дискретными командами при наличии обратной связи.
- Архитектура управления может быть реализована модульно, независимо от источника команд (нейроинтерфейс, кнопки, другие интерфейсы).

- Даже при высокой вариабельности сигнала возможно демонстрационное воспроизведение сценария движения.

### 5. Методология

5.1. Объект исследования

Мобильный электромеханический экзоскелет-вертикализатор с тремя приводами (два мотор-колеса и один привод шага).

5.2. Предмет исследования

Архитектура управления движением экзоскелета с использованием нейроинтерфейса как источника управляющих команд.

5.3. Ограничения
- управление дискретное;
- скорость ограничена;
- управление осуществляется в контролируемых условиях;
- цель — демонстрация и анализ устойчивости канала.

### 6. Метрики

- эллик выполняет движение на основе команд нейроинтерфейса
- количество корректно распознанных команд (%);
- среднее время реакции;
- количество ложных срабатываний;
- способность повторить сценарий движения;
- субъективная утомляемость пользователя.

### 7. Целевой вывод

Рассматриваемая архитектура может представлять интерес как основа для дальнейших исследований в области нейрореабилитации, включая спинальные травмы и постинсультные состояния, при условии интеграции стабильных биосигналов и клинической валидации.

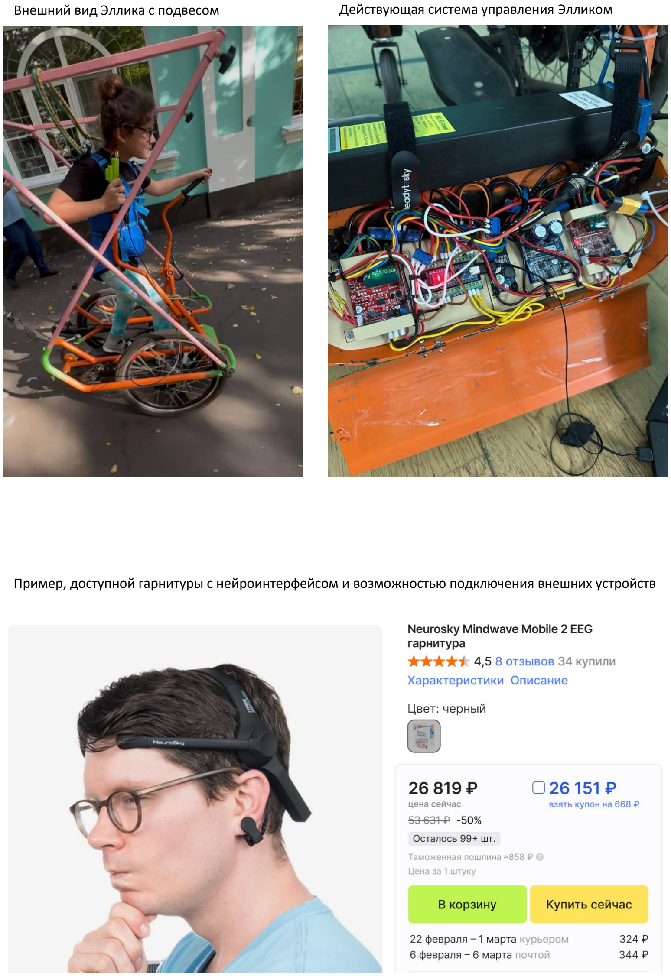
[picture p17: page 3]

Внешний вид Эллика с подвесом | Действующая система управления Элликом

Пример, доступной гарнитуры с нейроинтерфейсом и возможностью подключения внешних устройств

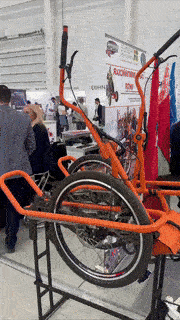
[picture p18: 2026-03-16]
media/moving_mechanism.gif

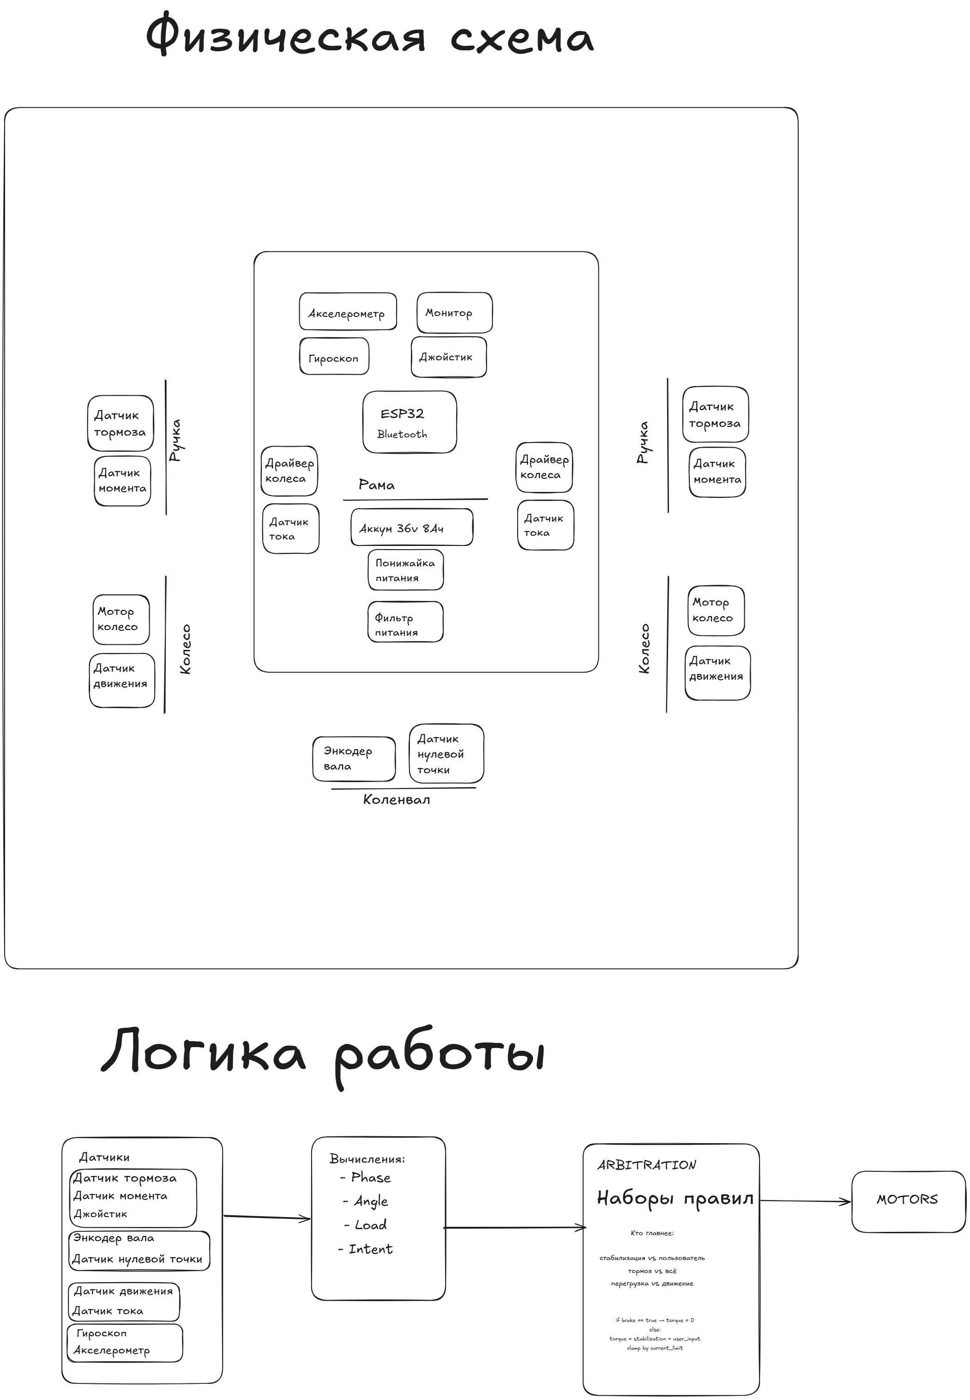
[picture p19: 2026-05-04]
firmware/FUTURE_IDEAS/SysChart.png

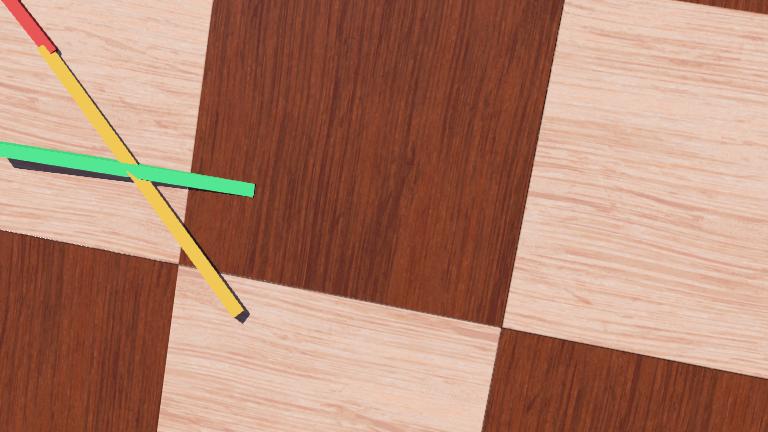
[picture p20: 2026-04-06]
simulation/webots/worlds/.Arena3819.jpg

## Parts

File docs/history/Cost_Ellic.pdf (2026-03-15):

№ п\п | Статьтя затрат | Сумма затрат, тыс. руб. | Описание
1 Ножницы | | 200 Первый прототип
2 Комбайн | | 600 Создано с участием Кафедры колесных машин Бауманскго университета. Отсутствовала система | привода.
3 Ладья | | 750 Полностью пересмотрен подход к кинематической схеме и реализации привода. Заменена | рычажная система на систему связанных ремнями блоков. Впервые применено консольное крепление колес.
4 Скутер | | 700 Вновь пересмотрена кинематическая схема. Найдено решение простой реализации рычажного | привода.
5 Шведка | | 650 Исследования влияния на эргономику переноса на одну сторону точки качания ручки и коленвала.
6 Разработка системы управления моторколес 1 | | 570 Разработка и производство управляющих контроллеров, разработка и производство печатных плат, | закупка компонентов, поверхностный монтаж, испытания, программироваание. Управление гироскопом.
7 Лебедь | | 870 Поиск решения проблем с жесткостью рамы.
8 Карета | | 650 Исследование влияния на устойчивость изменения геометрии рамы подъемом высоты точки | качания ручки.
9 Миникарета | | 550 Оптимизация рамы для транспортирования
10 Миникарета с приводом спереди | | 350 Исследование влияния изменения кинематической траектории стопы на эргономику, перенос | коленвала в переднюю часть скутера
11 Гусь синий | | 700 Уменьшение габаритных размеров и увеличение прочности. Изменена геометрия рамы.
12 Гусь оранжевый | | 900 Реализация и тестирование трехмоторной схемы
13 Кид | | 300 Разработана модель детской игрушки для сборки из стандартного алюминиевого профиля.
14 Раптор черный | | 960 Упрощена и уменьшена рама. Применено консольное крепление колес. Производство | поддерживающих колес.
15 Раптор моторный | | 570 Реализация малогабаритной моторной версии с консольным креплением моторколес.
16 Разработка системы управления моторколес 2 | | 760 Изменение требований к проектированию системы управления, перепроектирование контроллеров | управления, разработка и производство печатных плат, закупка компонентов, поверхностный монтаж, испытания, программирование.
17 Раптор белый | | 700 Упрощена и уменьшена конструкция скутера. Повышена технологичность производства и простота | сборки.
18 Разработка системы удержания Синий | | 100 Поиск системы удержания пилота, который не может удерживаться самостоятельно
19 Дорабока системой удержания и дистацонного | управления Оранж | 300 Испытания и доработка для применения на реальных детях ДЦП
20 Работы по стабилизации привода за счет | изменения геометрии звезд | 70 Компенсирует плавающий момент на счет переменных тактов ходьбы.
21 Разработка управления кареточным мотором | | 450 Механическая интеграция кареточного мотора в Оранж
22 Интеграция трехмоторной схемы | | 300 Разработка ПО, тесты, корректировка электромонтажа и электрической схемы.
23 Разработка инструкции по эксплуатации и | обучающих материалов | 30
24 Грант Фонда инноваций | | | Привлечено 2 млн руб.
25 Разработана и согласована с производством | КД | 700
26 Изготовлено 3 производственных образца | | 1000
27 Подготовлен научно технический отчет | | 300
Итого прямые вложения: | 14 030
1 Проведение выставки Фитнес | | 40
2 Проведение выставки Интеграция 2024 | | 40 Начало партнерства с центром Гросско
3 Проведение выставки Интеграция 2025 | | 40
4 Проведение выствики Робофинист | | 150 Непрерывная свободная эксплуатация 3 экземпляров (Гусь синий, Раптор черный, Раптор белый) на | протяжении трех дней массового мероприятия. Выявление слабых мест, дорабока конструкции
5 Подготовка конкурсной документации для | участия в грантах | 200 50 тысяч рублей за подготовку комлекта документации. Учтено подготовка 4 заявок в Фонд | содействия инновациям.
6 Ведение социальных сетей (20 млн | просмотров в тиктоке, ютуб, телеграм), производство видеоконтента | 600 https://www.youtube.com/channel/UCIquH_fNA_3huxtzbm07EMQ , https://www.tiktok.com/@ellicbike , | https://t.me/dvijtech , более 100 видеороликов
8 Создание и поддержание вебсайтов | | 200 https://ellic.tilda.ws/ , https://ellic.tilda.ws/cts
9 Патенты | | 300 Подготовка и содержание патентов России (на ременно-блочную конструкцию, устарел, не | поддерживается, на электрическую схему управления не поддерживается, на кинематическую схему - зарегистрирован, оплачен до 2029 года с возможностью продления)
10 Испытания на людях | | 620 Исследования в Госдарственном центре реабилитации Зеленограда: подготовлена | видеоинструкция по применению, разработана программа и методика испытаний, проведены испытания на людях, подготовлен отчет об испытаниях, разработана рекомендованная тренировочная программа.

11 Партнерское соглашение с Гросско
12 Партнерские отношения с РУТ МИИТ
13 Партнерские отношения с МИФИ
| Итого сопутствующие вложения: | 2 190
1 Работа основателя | 3 600 | с сентября 2019 года 6 полных лет * 200 тыс. руб. в мес * 0,25 ставки
Всего: | 19 820

Включены в общий пул расходов:
Аренда помещений
Аренда оборудования, транспорт Труд мастеров

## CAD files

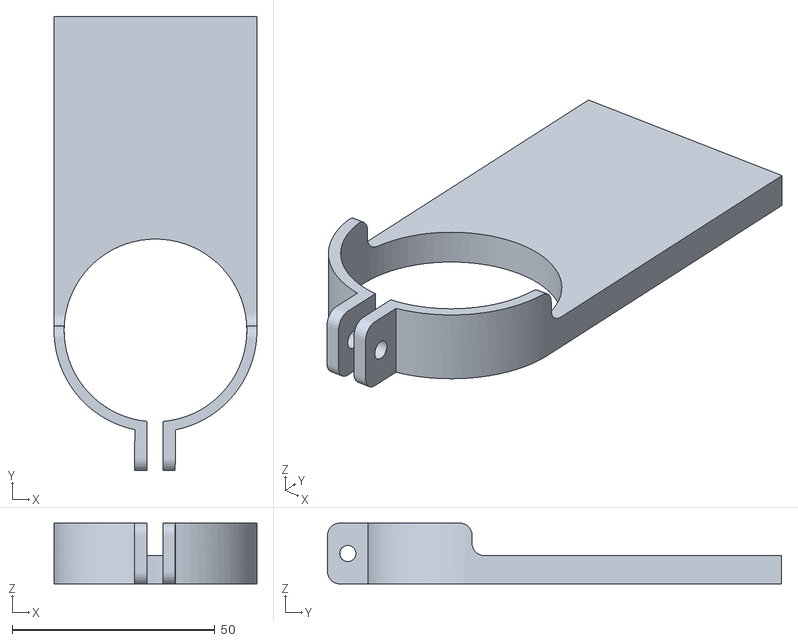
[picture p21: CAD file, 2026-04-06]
cad/manufacturing/3dPrint/derjOptEnc.stl
50.0 x 111.8 x 15.0

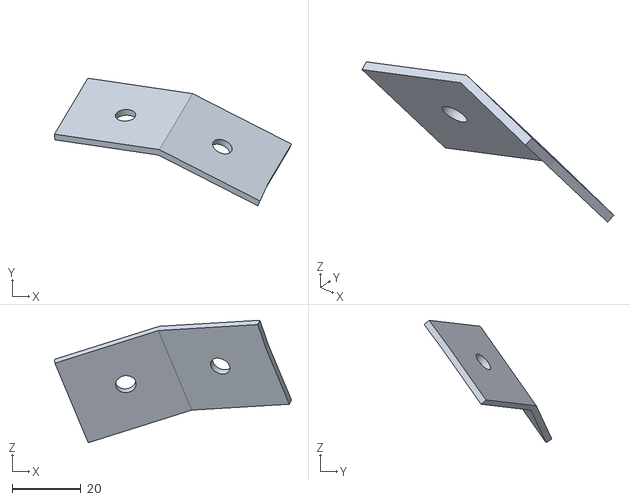
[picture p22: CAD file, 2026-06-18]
cad/manufacturing/3dPrint/Kronshtainy/2026-06-18/Body1.stl
69.1 x 37.2 x 35.7

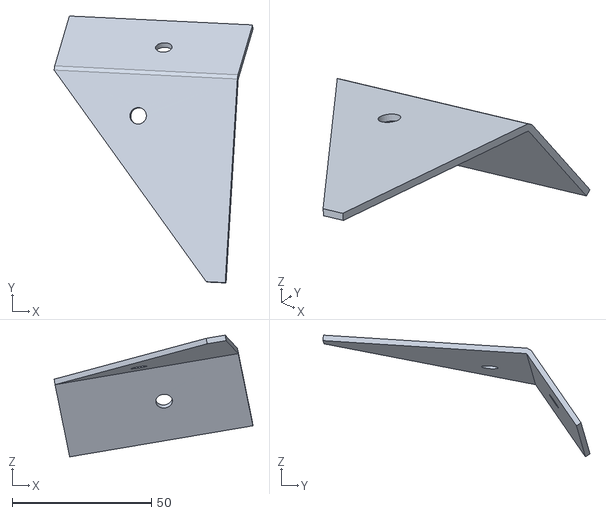
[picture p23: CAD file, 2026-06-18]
cad/manufacturing/3dPrint/Kronshtainy/2026-06-18/Vecher/VerhUgolVnutr.stl
71.5 x 96.0 x 43.8

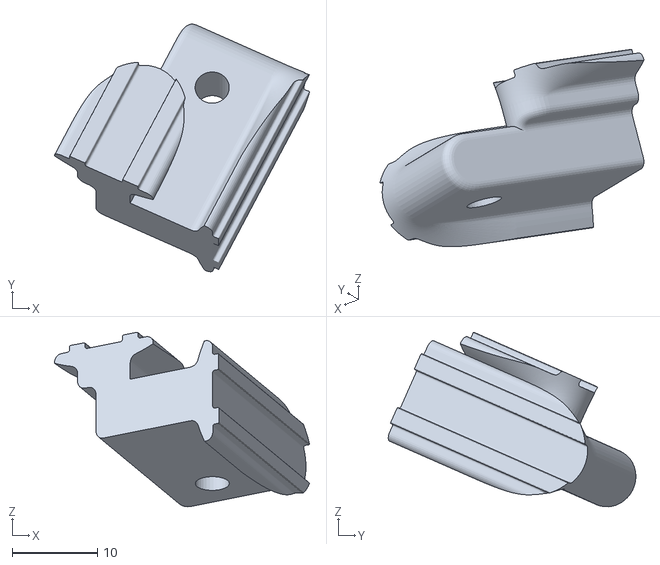
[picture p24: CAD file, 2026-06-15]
cad/manufacturing/3dPrint/Kronshtainy/VstavkaKluvNizUgol.stl
29.9 x 29.0 x 20.4

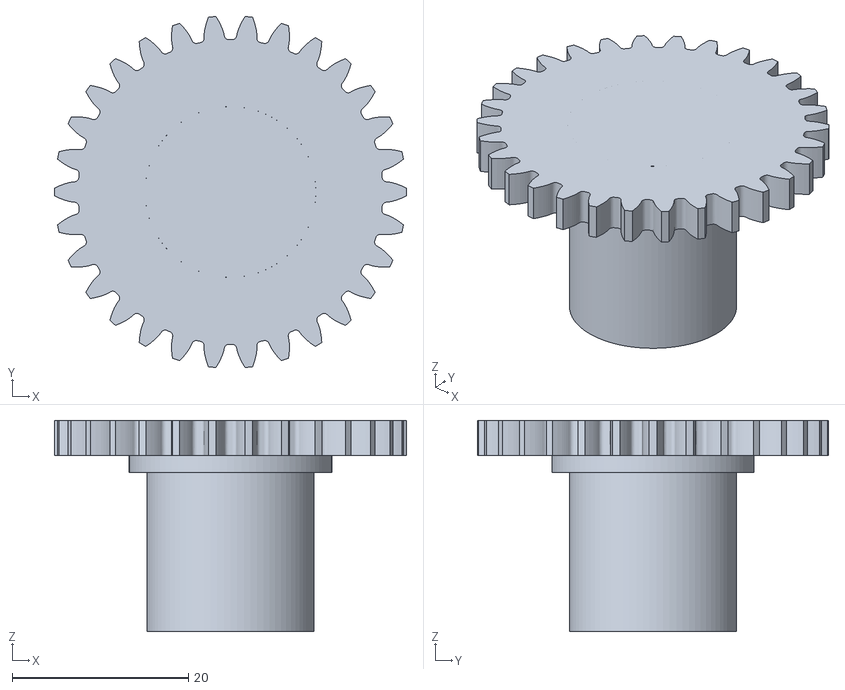
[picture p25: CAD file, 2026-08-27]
cad/manufacturing/3dPrint/ReductorEncodera/EncoderGear30.stl
40.0 x 39.9 x 24.0

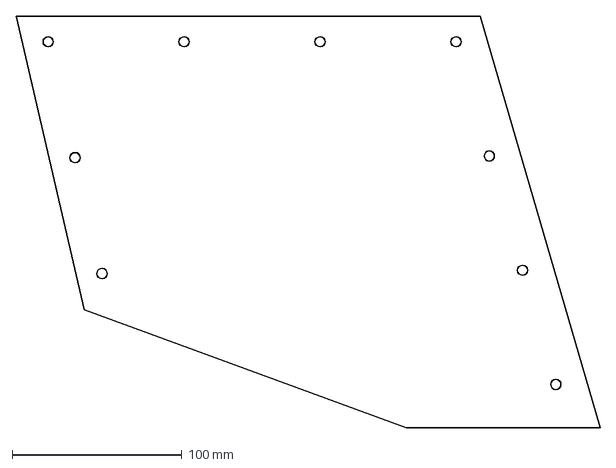
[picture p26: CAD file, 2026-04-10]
cad/manufacturing/CNAcraft/Carton8mm/dxfStomacPn.dxf
343.6 x 242.1 mm

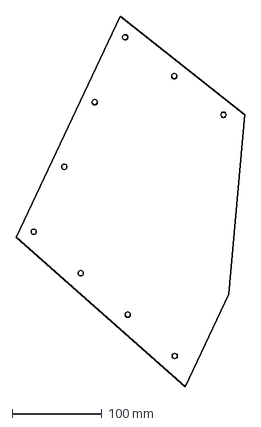
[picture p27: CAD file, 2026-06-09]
cad/manufacturing/CNAcraft/Carton8mm/Master/StomacPn(Mirror).dxf
255.4 x 413.9 mm

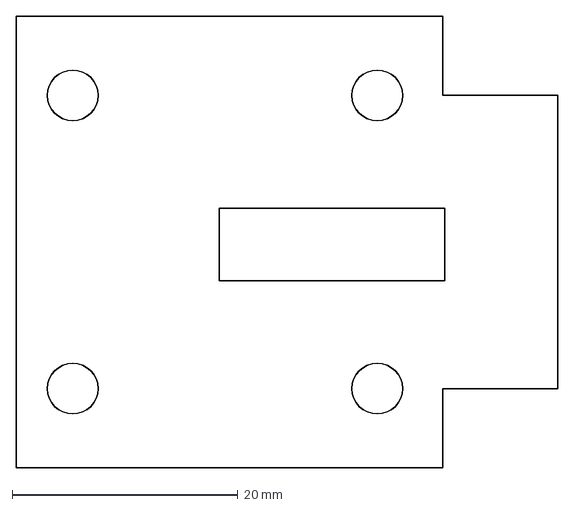
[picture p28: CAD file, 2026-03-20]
cad/manufacturing/laser/10mm/laser_mountplate_10mm_EllicV15.dxf
48.0 x 40.0 mm

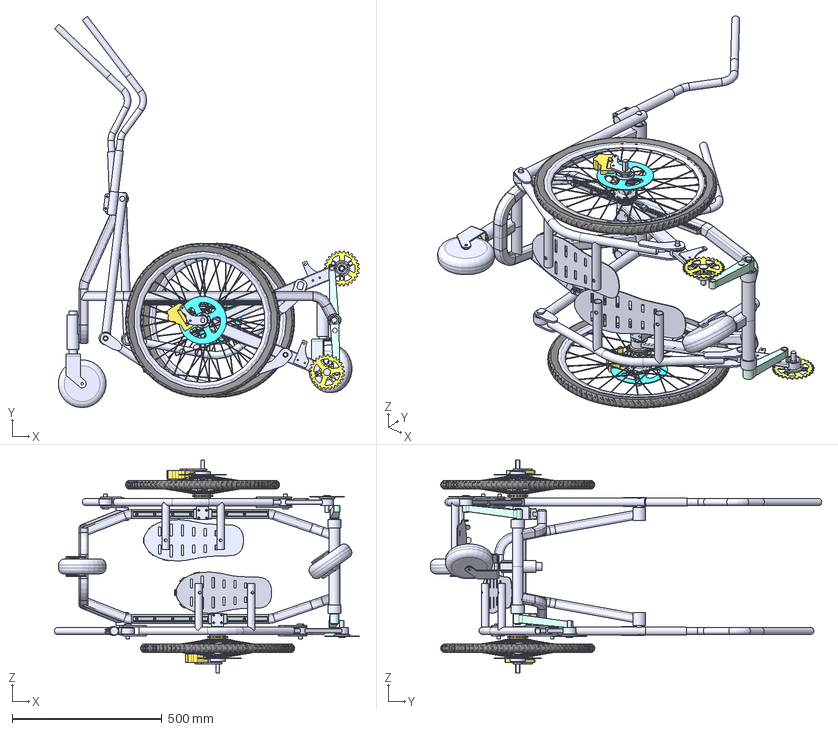
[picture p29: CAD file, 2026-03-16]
cad/step/EllicV14PROTOROS.step
1019.3 x 1307.6 x 710.4 mm
Ðàìà 3_® ã¬®«ç  ¨î< ª ®¡à ¡®â  ë©>
Óïîð çàäíèé - 3
Óïîð ïåðåäíè é - 3
Âòóëêà êîëåñ à - 3 x 2
Âòóëêà ðó÷êè 2 - 3 x 2
Êîðïóñ øàòóí à - 3 x 2
Âàë ñîåäèíèò åëüíûé - 3
Îñü øàòóíà - 3 x 2
RelsMalyy - 3 x 2
Âèëêà - 3 x 2
Âòóëêà âíóòð åííÿÿ - 3 x 2
Ñðåäíåå êîëå ñî - ýñêèç x 2
Êàðêàñ ðó÷êè-365-3_® ã¬®«ç ¨î< ª ®¡ à ¡®â ë©> x 2
Îñü ðó÷êè-365-3 x 2
Âòóëêà ìàëàÿ - 3 x 2
Óõî ëåâîå - 3 x 2
Óõî ïðàâîå - 3 x 2
Êîëüöî - 3 x 2
Êàðêàñ ðó÷êè (âåð õ)-365-3_® ã¬®«ç ¨î<  ª ®¡à ¡®â ë ©> x 2
Âòóëêà ðó÷êè - 3 x 2
Ðó÷êà (âåðõ)-365-3_® ã ¬®«ç ¨î< ª ®¡à ¡®â ë©> x 2
Âòóëêà òÿãè ï åðåäíÿÿ - 3 x 2
Âòóëêà òÿãè á îëüøàÿ - 3 x 4
Òÿãà äëèííàÿ (40õ20) - 3 x 2
Òÿãà êîðîòêà ÿ (40õ20) - 3 x 2
Òðóáà êàðêàñ à ïåäàëè-365-3 x 2
Óõî ïðÿìîóãîëüí îå êàðêàñà ïåäàë è-365-3 x 4
Óõî ñêðóãëåííîå êàðêàñà ïåäàëè-36 5-3 x 4
Òðóáà - 3
Òðóáà - 3_1
Shatun - 3 x 2
Stupnya - 3 x 2
Zvezda - 3 x 2
OsZvezdochkiSftuna - 3 x 2
Ugolok- 3 x 2
Çåðêàëüíî îò ðàçèòüÒðóáà - 3
Çåðêàëüíî îò ðàçèòüÒðóáà - 3_1
KaretkaMalaya - 3 x 2
Bolvanka 4 - 3 x 2
OsKolesa - 3 x 2
Tormoz - 3 x 2
Shtift - 3 x 2
Wheel_2-1-3-365-2 x 2
Star-1-3-365-2 x 2
Äèñê òîðìîçí îé-1-3-365-2 x 2
MashinkaTormoznaya_2-3-365-2 x 2
OsRuchek - 3 x 4
ShaybaVtulkiRuchki - 3 x 2

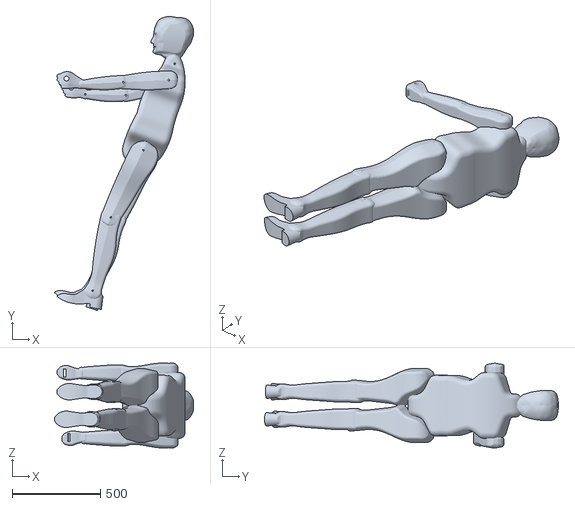
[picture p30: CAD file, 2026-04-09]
cad/stl/ChelSTL.stl
788.6 x 1665.4 x 480.0

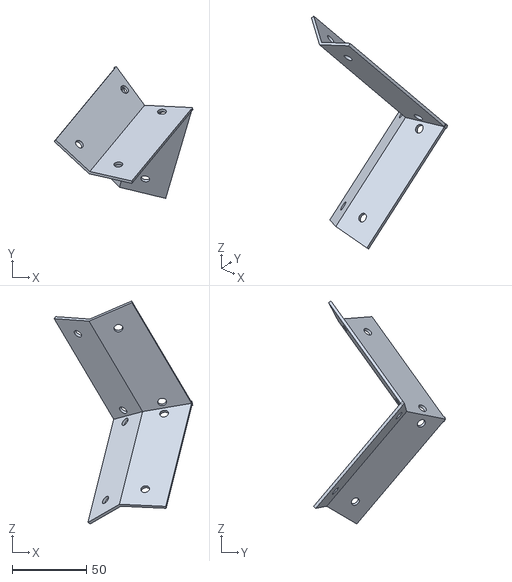
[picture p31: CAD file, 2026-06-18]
cad/manufacturing/3dPrint/Kronshtainy/2026-06-18/Vecher/StomacNutr.stl
93.2 x 88.6 x 149.8

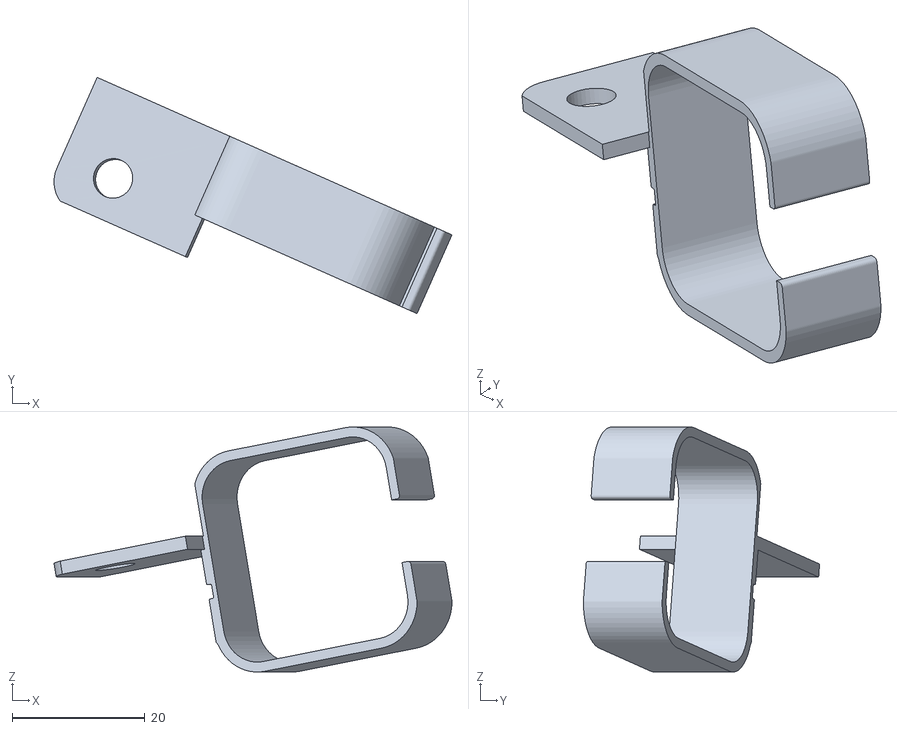
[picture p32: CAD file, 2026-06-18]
cad/manufacturing/3dPrint/Kronshtainy/2026-06-18/ZacepPlBok.stl
60.1 x 35.6 x 37.0

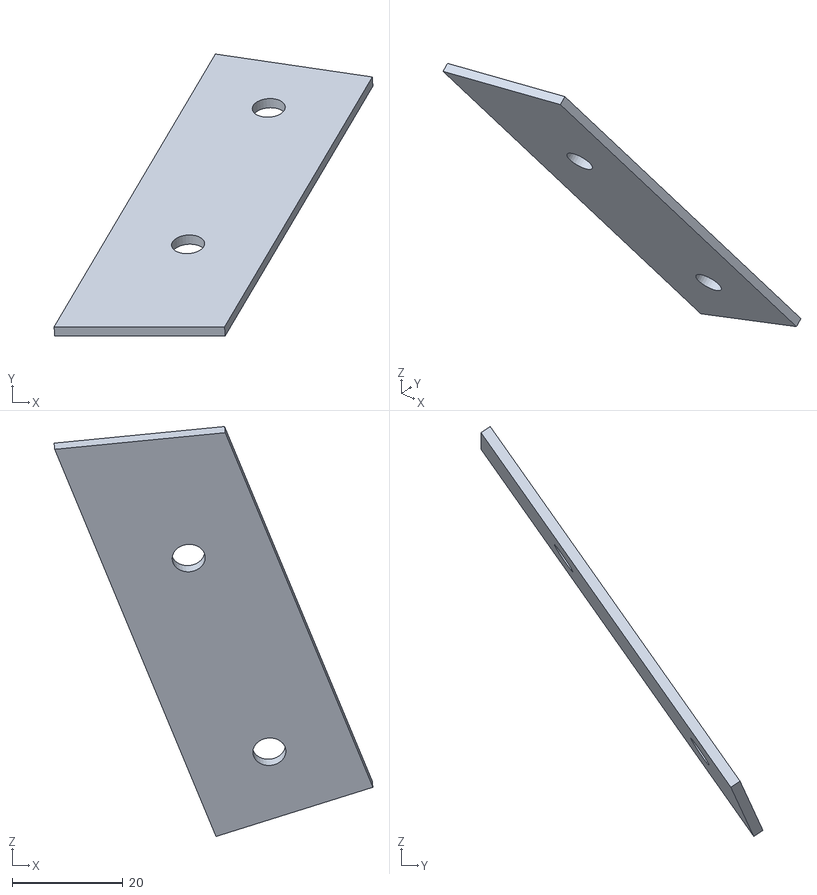
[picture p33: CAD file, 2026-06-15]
cad/manufacturing/3dPrint/Kronshtainy/LegNiz.stl
57.6 x 50.9 x 74.1

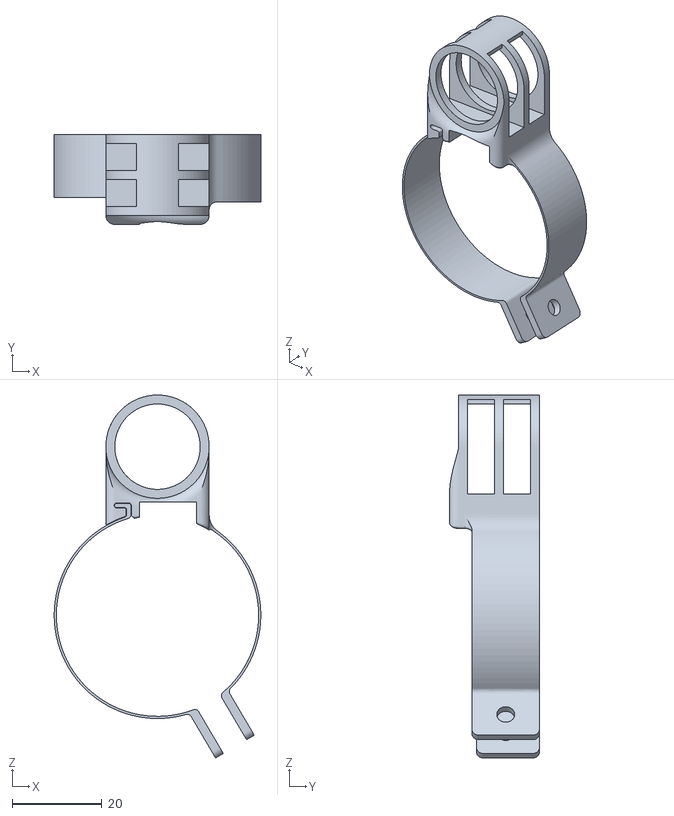
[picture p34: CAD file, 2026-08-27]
cad/manufacturing/3dPrint/ReductorEncodera/EncoderHolder.stl
46.0 x 20.0 x 80.8

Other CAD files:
cad/manufacturing/CNAcraft/Carton8mm/dxfBreastPn.dxf
cad/manufacturing/CNAcraft/Carton8mm/Master/MasterObves.dxf
cad/manufacturing/laser/10mm/laser_frontplate_10mm_ellicV15.dxf
cad/manufacturing/3dPrint/Kronshtainy/2026-06-18/Vecher/NeNorm(Mirror).stl
cad/SolidWorks/EllicV14ParasolidEng.x_t
cad/fusion/DESIGN/Ellic_Obves.f3d
cad/fusion/DESIGN/KronshtainObvesa.f3d
cad/fusion/EllicV14FUSION.f3d
cad/fusion/PARTS/Encoder/ReductorEncodera.f3d
cad/fusion/PARTS/OptEnc/derjOptEnc.f3d
cad/fusion/PARTS/WHEELS/CronsHobot.f3d
cad/fusion/PARTS/WHEELS/Motor.f3d
cad/fusion/PARTS/WHEELS/SBR_Koleso_Stupitca.f3d
cad/fusion/PARTS/WHEELS/Wheel_2-1-3-365-2.f3d
cad/manufacturing/3dPrint/Kronshtainy/2026-06-18/FrontStakanObvesa.stl
cad/manufacturing/3dPrint/Kronshtainy/2026-06-18/KluvNizUgol (1) (2).stl
cad/manufacturing/3dPrint/Kronshtainy/2026-06-18/NeNorm.stl
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

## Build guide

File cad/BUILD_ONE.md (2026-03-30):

# 🛠️ BUILD ONE ELLIC

### Experimental Build Guide (Real-World Version)

This document describes how a **real Ellic machine is actually built in practice**.

It is not theoretical — it reflects the **actual workflow, tools, and decisions** used during prototyping.

The goal is simple:
👉 help you understand **what you really need to build one**

<table align="center">
  <tr>
    <td align="center" valign="middle">
      
    </td>
    <td align="center" valign="middle">
      
    </td>
    <td align="center" valign="middle">
      
    </td>
  </tr>
</table>

---

# 🚀 What You Are Building

Ellic is a **human-scale walking machine** driven by an **elliptical linkage mechanism**.

It behaves somewhere between:

- 🛴 a scooter  
- 🚶 a walking machine  
- 🤖 a mech-like vehicle  

This is not just transport — it is a **mechanical platform + experimental interface system**.

---

# ⚠️ Important Warning

This is a **mechanically active experimental system**.

Risks include:

- moving linkages ⚙️  
- structural loads 🏗️  
- electric drive systems ⚡  

👉 Build only if you understand:
- mechanical systems
- basic electronics
- safe testing practices

Always test:
- at **low speed**
- with **support**
- with **emergency stop ready**

---

# 🧠 How the Build Actually Happens

The build is **not linear engineering perfection**.

In reality, it looks like this:

👉 Mechanics first  
👉 Parts sourcing in parallel  
👉 Electronics later  
👉 Software last  

---

# 🔧 1. Mechanical Fabrication (Core Stage)

This is **80% of the real work**.

### Required tools:

- angle grinder (minimum viable) 🪚  
- tube cutting + bending tools 🔩  
- welding setup 🔥  
- (optional but ideal) laser cutter ✂️  

### Materials:

- steel tubes (main structure)
- standard bearings (used as-is)

💡 Design principle:
> Bearings are selected to fit directly into standard tubes  
(no complex machining required)

---

# ⚙️ 2. 🚲 Bike Components & Machined Parts (Outsourced or DIY)

You will need:

- standart bike components
- simple shafts  
- connection axles  

These are:

- 🟢 cheap  
- 🟢 simple  
- 🟢 easy to outsource  

👉 You can order them from a local machinist.
👉 Option:
- source yourself  
- or order a **pre-selected kit from the project. just ask me somhere here**

---

# 🔩 3. Laser-Cut Parts (Highly Recommended)

For:

- brackets  
- mounts  
- structural connectors  

👉 A **laser cutter** significantly improves:

- precision  
- assembly speed  
- rigidity  

Without it:
- you can improvise, but accuracy will drop

---

# 🧱 4. Optional: 🎨 Body & Styling 3D Printing

- covers  
- visual design  
- plywood 🪵  
- foam panels 🧩  
- composite / carbon panels  
Not required for function, but important for experience.

---

# 🔌 5. 🔗 Wiring & Electronics Assembly 

After mechanics works — add electronics.

### Core components:

- ⚡ 2× motor wheel drivers  
- 🔋 battery (36V, 4–8Ah)  
- 🔽 voltage step-down converter  
- 🧠 ESP32 controller (WiFi + BLE)  
- 🎮 joystick  

Everything is mounted directly on the framу CONNECT:

- motor drivers → motor wheels  
- battery → drivers  
- ESP32 → control signals  
- joystick → ESP32  

---

# 🧪 6. First Functional Mode (Scooter Mode)

At this stage: 👉 The machine works as a **drive platform**

Control logic:

- joystick → ESP32  
- ESP32 → motor drivers  
- motor wheels → motion  

You now have:

🟢 a controllable vehicle  
🟢 basic mobility  
🟢 testable system  

---

# 🤖 7. Mech Mode (Extended System)

Now the interesting part.

You can connect:

- 🥽 VR headset  
- 🎮 same joystick  
- 💻 Unreal Engine system (from repo)

Result:

👉 The machine becomes part of a **mixed-reality mech system**

You can:

- control movement physically  
- control a mech avatar  
- interact in AR/VR space  

---

# 🎯 8. MechSport Layer

With full setup:

- 🎮 player controls mech  
- 🚶 machine mirrors motion  
- 🔫 virtual weapons controlled by joystick  

---

# 🧭 Build Summary (Reality)

Real build flow:

1. 🔧 fabricate frame  
2. ⚙️ assemble linkage  
3. 🧱 install machined parts  
4. 🚲 add bike components  
5. 🔩 mount brackets (laser-cut)  
6. 🔌 install electronics  
7. 🎮 test scooter mode  
8. 🤖 connect VR system  

---

# 💰 Cost & Time

Typical prototype:

- $3,000 – $7,000 (DIY build)
Prebuilt system:
- ~$20,000  
- solo builder: **2-4 months**  

---

# All the draws, CAD models, firmware i try you can [get here]() 

If not just ask me dselog@gmail.com 

[README.md](README.md)

[START_A_TEAM](START_A_TEAM.md)

---

<a href="https://github.com/Dvijtech/ellic/stargazers" target="_blank" style="text-decoration:none;">
  <kbd>⭐ Star the repository</kbd>
</a>

<a href="https://github.com/Dvijtech/ellic/fork" target="_blank" style="text-decoration:none;">
  <kbd>🔧 Fork the project</kbd>
</a>

<a href="https://github.com/Dvijtech/ellic/issues" target="_blank" style="text-decoration:none;">
  <kbd>💡 Open issues with ideas</kbd>
</a>

<a href="https://twitter.com/intent/tweet?text=Check+out+this+project+on+GitHub&url=https://github.com/Dvijtech/ellic" target="_blank" style="text-decoration:none;">
  <kbd>📢 Share the project</kbd>
</a>

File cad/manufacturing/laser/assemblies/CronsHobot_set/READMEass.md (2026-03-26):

#CronsHobot# looks like 

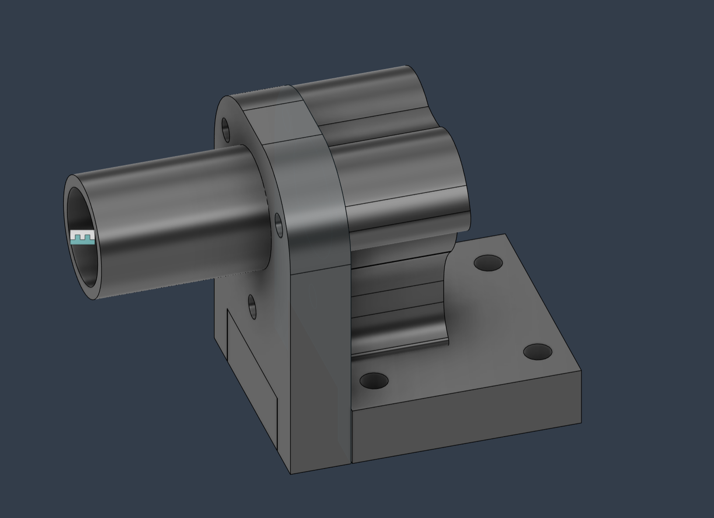
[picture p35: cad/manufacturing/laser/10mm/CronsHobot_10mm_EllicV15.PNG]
# CronsHobot_10mm_EllicV15


# CronsHobot parts are:

[cad/manufacturing/laser/10mm/laser_frontplate_10mm_ellicV15.dxf](/cad/manufacturing/laser/10mm/laser_frontplate_10mm_ellicV15.dxf)

[cad/manufacturing/laser/10mm/laser_mountplate_10mm_EllicV15.dxf](/cad/manufacturing/laser/10mm/laser_mountplate_10mm_EllicV15.dxf)

[cad/manufacturing/laser/10 mm/laser_tavr_10mm_ellicV15.dxf](/cad/manufacturing/laser/10mm/laser_tavr_10mm_ellicV15.dxf)

Hobot look at model [cad/fusion/PARTS/WHEELS/CronsHobot.f3d](/cad/fusion/PARTS/WHEELS/CronsHobot.f3d)

Easy assembly

Welding

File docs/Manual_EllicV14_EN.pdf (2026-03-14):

# Ellipse for wellness and beauty Instruction manual www.ellic.bike

Dear customer! Thank you for choosing Ellic and congratulations on buying a modern nordic walking machine on wheels. We are sure that with proper maintenance and proper operation, your trainee will serve you faithfully for a long time, and will deliver many pleasant, exciting hours during skiing. Your trainee will provide you with functionality, comfort and safety while observing the rules of movement set out in this guide. We urge you to read this guide carefully before you start training for the first time.

Content:
1. General device of the trainee
2. Rules of trainee control
3. Basic safety rules during the operation of the trainee
4. Basic rules for the operation of the trainee
5. Warranty Information
Warranty card

### 1. General device of the trainee

Ellic is a rather complex design and, in fact, is the next evolutionary step in the development of the bicycle, bringing the trainee closer to the wheeled exoskeleton. At the same time, a significant number of parts the trainee borrowed from the bicycle. At the heart of the trainee is a frame on which all its other elements are mounted. The main ones are listed below.
The device contains a spatial symmetrical frame having side longitudinal guides, carriages that move forward and backward along longitudinal guides, two wheels fixed with their axis on carriages and hand levers connected to pedals and wheels.
General view of the device | Side view

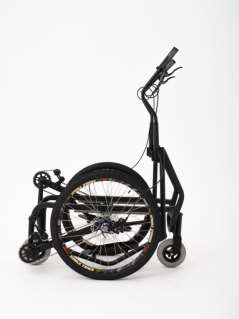
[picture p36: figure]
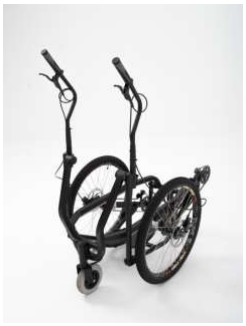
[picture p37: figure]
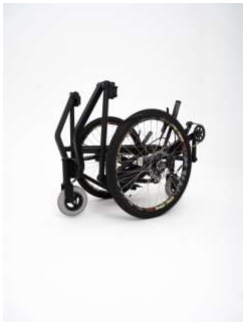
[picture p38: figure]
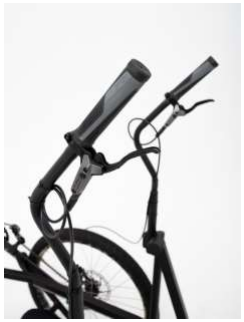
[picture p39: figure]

View with handles folded | View of hand levers with brakes

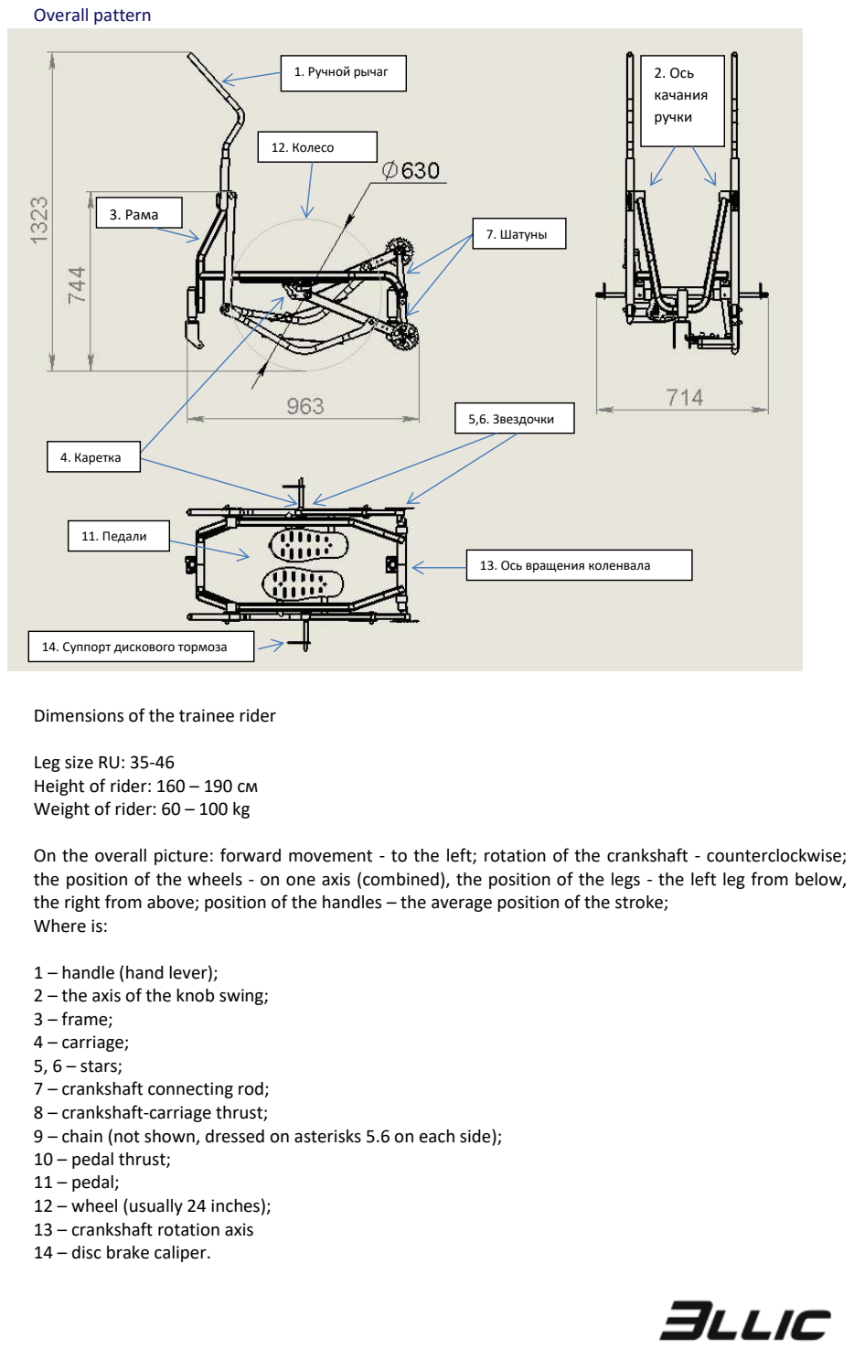
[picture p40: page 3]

Overall pattern

Dimensions of the trainee rider

Leg size RU: 35-46
Height of rider: 160 – 190 см
Weight of rider: 60 – 100 kg

On the overall picture: forward movement - to the left; rotation of the crankshaft - counterclockwise; the position of the wheels - on one axis (combined), the position of the legs - the left leg from below, the right from above; position of the handles – the average position of the stroke;
Where is:

1 – handle (hand lever);
2 – the axis of the knob swing;
3 – frame;
4 – carriage;
5, 6 – stars;
7 – crankshaft connecting rod;
8 – crankshaft-carriage thrust;
9 – chain (not shown, dressed on asterisks 5.6 on each side); 10 – pedal thrust;
11 – pedal;
12 – wheel (usually 24 inches);
13 – crankshaft rotation axis 14 – disc brake caliper.
8. Тяга коленвала - каретки
1. Ручной рычаг
3. Рама
4. Каретка
11. Педали
12. Колесо
2. Ось
качания
ручки

5,6. Звездочки

7. Шатуны
13. Ось вращения коленвала
14. Суппорт дискового тормоза

The axles of the wheels are connected to the carriages and the crankshaft. The axis of rotation of the crankshaft 13 is located perpendicular to the longitudinal axis of the forward motion of the carriages 4. The crankshaft has 6 sprockles on the connecting rods to transmit rotational motion. The axles of the wheels 12 are also equipped with sprocket 5 with a ratchet mechanism. The crankshaft is connected to the axle of each wheel by means of a crankshaft thrust 8 and a chain transmission 9. Thus, the rotational motion of the crankshaft is converted into the rotation of the wheels and their forward-backward movement along the longitudinal guides.
The device also contains hand levers 1. Hand levers 1 swing on hinges fixed on the frame 3. Lever swing axis – 2.
To the lower end of each hand lever 1 on the hinge is attached pedal thrust 10. At the other end of the thrust is fixed pedal 11, on which the rider stands with his foot. The thrust of the pedal 10 hinge is associated with the thrust of the crankshaft 8.
The rider acts with hand levers 1 (hands move back and forth) and pedals 11 (move along an elliptical trajectory) imitating the movements of the legs and hands that a person makes when walking. The pedals rotate back and forth. When the pedals rotate forward, the trainee moves the wheels synchronously with the legs and goes forward. When the pedals rotate back, the trainee moves the wheels synchronously with the legs but does not go.
For convenience, the trainee is equipped with auxiliary wheels in front and rear.
It is forbidden to make changes to the design of the trainee without the written consent of the manufacturer. Maintenance of the trainee is recommended to be carried out in specialized or bicycle workshops.

### 2. Rules of trainee control

Ellic sensual trainee, it gives new emotions from a harmonious walk on wheels, and to get used to walking on wheels you need to train.

Rule #1
The entrance to Ellic is at the rear and the exit from Ellic is at the front.
To enter Ellic, approach it from behind. Grab the hand levers and hold the brakes. Step over the frame, stand on the bottom pedal. To stand on the Ellic, always step on the bottom pedal first. The lower pedal must be stepd on to avoid pedaling backwards. Getting up on the trainee first step on the lower pedal. To get out of Ellic, always go ahead. Pull over. Remove both brakes. Step on the crossbar under your feet and go forward. Ellic is designed so that there are no objects in front of the rider that prevent him from going forward.

Rule #2
Always stand on the pedals with two feet.
Do not tear the soles off the pedals. Combine the center of the foot with the center of the pedal. In order to avoid injuries, shoes, and even more so the bare parts of the foot (it is not recommended to ride barefoot) should not protrude beyond the edges of the pedals.

Rule #3
Ellic walks with his feet.
As in life - walk with your feet and help with your hands. If you move your legs incorrectly, you will not be able to go on your hands. Catch the balance on your feet. Ellic steps to repeat the biomechanics of the human body. The Ellic wheels move simultaneously with the rider's legs. This ensures the balance of the rider in motion. Arms and legs move synchronously.

Rule No4
If you pedal backwards, then the wheels will walk with the legs, but the Ellic will stand still.

Rule No5
The easiest start is when the front foot presses on the pedal.
It is easier to start from the foot position from the front than from the foot position from above.

Rule No6
To go easily you need to find a balance.
Do not pile on the levers and do not hang on them. As always, the balance is somewhere in between. Do not worry if you do not immediately find it - you will be insure by auxiliary wheels and the balance will definitely come with time. To go to Ellic you will have to deal with and ride with your head proudly raised.

Rule No7
For braking, always clamp both brakes at the same time to avoid twisting, stalling and falling.

Rule No8
First learn to drive straight and only then turn.
First, learn to drive straight and only then begin to learn to turn on the go. Do not be afraid that it is not possible to turn right away. First you need to get used to Ellica little. To do this, just learn to drive straight. And the slower the better. If you can take your time, you will feel your body better and learning will be easier. In the first lesson, you need to learn how to drive straight.

Rule #9
Do not rush and do not hurry.
For a full ride, you need your body to master and react itself. It is impossible to understand how to ride a bicycle, it is necessary to feel. Usually this requires from one to three classes. This is especially true of turns and slopes. Be extremely careful and collected when managing Ellic. Try to feel Ellic.

Rule No10
Walking and rolling are not the same thing.
To walk it is to move your legs. It's when the wheels are going.
You can roll and not walk. This means that the wheels can go even if you don't move your legs. For example, coasting or down the slide.
But you will not be able to walk (move your legs) forward on the spot. Ellic will go ahead. It's like a regular bike.

Rule No11
You can't walk and turn at the same time.
You can roll and turn at the same time. To turn you need to roll and not walk. That's the hardest rule. But having mastered it, you will not be stopped.

Rule No12
The closer the wheels are aligned, the easier the turn.

Rule #13
Ellic can turn in place.

Rule No14
Ellic can walk backwards

Rule No15
Levers can not be steered, but you can steer.

Rule No16
Do not make excessive efforts.

Ellic moves pretty easily. If you make uncomfortable efforts for yourself, then you are doing something wrong. Relax a little and think about what you do and which of the rules you do not follow.

Rule No17
You can't just take and learn all the rules at once.

How do I rotate?
There are several ways to turn on Ellic. Here they are listed as the complexity increases.
1. Turn in place without movement.
2. Turn in motion.
3. Steering with manual levers on the go.
4. Turning from the start with a platoon of pedals.
Let's consider ways to rotate in order.
1. Turn in place without movement. Necessary for beginners, as it allows you to get out of deadlock situations without leaving Ellic. In the future, when you master the turn in motion, this method will be used only in rare cases.
- Move the pedals back put your feet apart so that the back is the foot in which direction you want to turn.
- Squeeze both brakes.
- Without releasing the brakes, take a step back (scroll the pedals back half a full turn). Ellic will rotate around its axis and the hind leg will move forward.
- Release the brakes and look around.
- If the rotation angle is insufficient, then repeat the cycle.
2. Turn in motion.
- You can roll and turn at the same time, but you can not walk and turn at the same time. That's the hardest rule. But having mastered it, you will not be stopped.
- Ellic turns best when the axles of the wheels are aligned. The farther apart the wheels are placed, the greater the turning radius and the lower the responsiveness to the control effect. Control the alignment of the wheels before turning. At first it will seem complicated, but after a few repetitions you will bring it to automatism.
To turn on the go you need:
- Dial a small speed (you can quickly, but enough and small);
- Stop walking;
- Combine the axles of the wheels;
- To turn right (left) press the right (left) brake.
- Control the speed, remember that the lower the speed the safer the maneuver. Learn and make turns at the safe speed of your leisurely walking.
3. Steering with manual levers on the go.
To shift the course of movement of the trainee on the move to the right, you need to pull the right lever with additional effort.
To shift the course of movement of the trainee on the move to the left, you need to pull the left lever with additional effort.
- Do not tear the sole from the pedals and do not transfer the weight of the whole body to the upper pedal and the far lever. These actions increase the height of the Ellic center of gravity with the rider and, if controlled inexperiencedly, can lead to rollover.
- It is not recommended to use this technique for turns in the first lesson.
4. Turning from the start with a platoon of pedals.

- To turn left, place the lever of your left hand forward and the right back.
- With the application of force, pull the left lever back, and push the right lever forward with force.
- Simultaneously create the added force on the front pedal.
- Look for a position in which the levers and pedals create maximum torque. Usually such a moment is created when the upper pedal has already passed the extreme upper point but has not yet reached the extreme front point.
- Passing segments of the maximum torque by turning the pedals back, return the levers to the maximum torque position.
- Do not tear the sole from the pedals and do not transfer the weight of the whole body to the upper pedal and the far lever. These actions increase the height of the Ellic center of gravity with the rider and, if controlled inexperiencedly, can lead to rollover.
- It is not recommended to use this technique for turns in the first lesson.

How do I step back?
Ellic can step backwards. To do this, you need to pedal (walk) back and alternately clamp the left and right brake, as if clinging to the road with your back foot and push it forward.
Let's go through the points:
1. Stand up so that the right leg is behind. You can set this position in place by scrolling the pedals back.
2. Clamp the right brake. Without releasing the brake, take a step back (scroll the pedals back half a full turn), until the right foot is in front.
3. Release the brake.
4. Ellic takes a step back and the left leg is behind.
We do the same for the other leg.
1. Clamp the left brake. Without releasing the brake, take a step back (scroll the pedals back half a full turn), until the left leg is in front.
2. Release the brake.
3. Ellic takes a step back and the right leg is behind.
Repeat as many times as necessary.

Exercises for learning
1. Stand on the engine (remember the lower pedal?)
alternately lean on the front and rear auxiliary wheels. Repeat 10 times.
Pedal back. Do you feel the wheels following your legs?
2. As in walking, you have 4 beats of movement. For simplicity - choose your favorite leg. Slowly pedal back. Pay attention to the beats
Favorite leg below
Favorite leg in front
Favorite leg on top
Favorite leg behind.
We're close to trying a ride. But first, try swinging forward backwards in each different position. The back is straight, balance with your legs. You are ready to go if you can let go of your hands and stand flat on your feet.
3. Let's start.
To do this, we work with our feet. 90% of the energy to the movement is given by the legs. It is better to start going leaning on the front auxiliary wheel. If you can't move- stop. Think about what you're doing wrong. Without stopping the contact of the front auxiliary wheel with the ground, scroll the pedals back. Stop the rotation in different positions and try to catch the moment of start.

Don't try to wrest leverage. Don't hang on the levers. The application of excessive effort to the levers shifts the balance and turns the Ellic. Ellic is like walking - moves with your feet.
If you put in an effort and Ellic doesn't respond or go, then you're doing something wrong.
Excessive efforts do not need to be applied.
If you feel like you're putting in a hell of an effort, stop.
Think about what you're doing.
To reset the impressions - scroll back the pedals.
4. Exercises for straight skating. Repeat each exercise 3 times.
Take two steps, stop walking and keep rolling.
Take two steps, put your right foot down, stop walking and keep rolling. Take two steps, put your left foot down, stop walking and keep rolling. Take two steps, stop walking, keep rolling, without stopping, pedal back.

Attention!
Do not accelerate until you feel how the trainee is controlled. Avoid sudden braking and cornering. In the first lessons, it is not recommended to move down from the slides. Remember that on Ellic you ride a horse and are responsible not only for yourself but also for others.

How to adjust the brake pads?
Disc mechanical brakes are installed on your trainee, from time to time it is necessary to check the position of the brake pads relative to the brake disc.
Disc mechanical brakes have one fixed pad and one movable pad driven by a brake cable from the brake handle. Both pads and the mechanical disc brake housing are subject to position adjustment. You should start with adjusting the latter.
1. Loosen the mounting bolts that attach the brake body to the carriage;
2. Insert the brake housing so that the brake disc passes strictly along the center of the slot in the brake housing;
3. Tighten the mounting bolts, preventing distortion of the brake body;
4. By adjusting on the inside of the brake housing, place the fixed brake pad at the minimum distance to the brake disc, but not allowing it to be touched by the disc.
5. By adjusting on the outside of the brake housing, similarly set the movable brake pad so that the clearance is not more than 1 mm.
6. Check the brake operation. Full pressing of the pads to each other (through the brake disc)
7. Adjust the idle stroke of the handle with a rotating screw on it.
A properly adjusted mechanical disc brake should confidently stop the bike when pressing the brake handle and at the same time not prevent the rotation of the brake disc when the brake handle is released. It is permissible to lightly touch the disc with pads, if this does not cause tangible braking of the wheel. Hydraulic sled brakes are higher adjusted for the type of brake drive and the fact that most hydraulic disc brakes have two self-priming movable pads. Fine-tuning the position of the brake body and, accordingly, the brake pads on the hydraulic brakes, as well as pumping the brakes, is better to entrust to a qualified mechanic.

### 4. Basic safety rules during the operation of the trainee

3.1. Riding on the trainee is associated with a certain risk and increased danger. To minimize the risk, we kindly ask you to adhere to the Rules of the Road, as well as to comply with the basic safety requirements associated with the specifics of movement on the trainee. It should be understood that there are no such precautions with which it was possible to eliminate any risk.
3.2. We strongly recommend the use of bicycle gloves with a special lining on the palm of your hand. They will protect your palms from injury in case of an accidental fall and, in addition, will provide a more reliable grip of the levers and reduce vibrations passing from the ground through the parts of the trainee to the hand levers.
3.3. Do not ride on the trainee, listening to music or other audio signals through headphones, as in this case you will not be able to quickly monitor the situation around you by ear. Departure on the trainee on public roads is not allowed.
3.4. Make sure that the brakes of the trainee work efficiently, and always maintain your trainee in good technical condition. When braking, control the braking force, preventing excessive braking. Try to brake with the same intensity with both brakes.
3.5. Watch for potholes, ditches and other dangerous objects on the road. In case of sudden detection of an obstacle on the road, in no case do not go around it on the left, so as not to interfere with traffic participants. Remember: a bicycle, scooter or car approaching from behind, most often not able to change direction quickly enough to avoid a collision with a sharply shifted to the side of the object in front.
3.6. When riding on the trainee, wear bright, noticeable clothes. This will make you much better visible to other road users. In most cases, the driver, noticing an obstacle in advance, will do everything possible to overtake him as safely as possible. Clothing should not constrain movements, while it should not be very spacious in order to avoid getting or winding its parts in the moving parts of the trainee: stars, connecting rods, spokes, rods, carriages. We advise you to buy specialized clothes for training in the appropriate stores.
3.7. It is strictly forbidden to dismantle reflectors (cataphotes) from bicycles. The trainee should have a front reflector of white color, rear - red and side - yellow.
3.8. Transport the trainee through public roads, railway or tram tracks only in dismounts and at right angles.
3.9. Riding on the trainee at night or in conditions of limited visibility (in the dark, in fog, in the rain, at dusk) is extremely dangerous and imposes additional requirements on the rider. We recommend you to refrain from skiing in such conditions. We also draw attention to the fact that skiing in the dark without additional lighting equipment (lanterns, beacons) is especially dangerous, and in most European countries it is prohibited by law. If you use lighting equipment powered by batteries, then before the trip make sure that it is serviceable, as well as that the batteries (accumulators) are fully charged. ATTENTION! The risk of injuries and accidents increases with improper use of the trainee, namely:
- jumping on the trainee;
- riding on branches, tree roots, garbage or other obstacles;
- performing tricks on the trainee;
- fast riding, participation in races or downhill (downhill);
- riding in an unusual way;
- emergency braking, including one brake;
All of the above are examples of improper use, which increases the load on all parts of the trainee. High load can cause breakdown, which can increase the risk of injury and injury. To reduce the risk of injury and accidents, do not allow the above types of operation.
3.10. Skiing in rainy weather or in conditions of high humidity
Remember that in wet weather, the brakes lose some of their efficiency, so always consider this when driving. It should also be remembered that a wet road is more slippery than dry, so when driving on a wet or wet road, control your speed, avoid sharp maneuvers and sudden braking. Be especially careful when crossing railway or tram tracks, public roads, metal surfaces, road markings, which in wet weather are especially slippery.
3.11. Cross-country skiing, as well as in places of rest
The growing popularity of individual means of transport causes additional requirements for riders riding in parks, recreation areas, ski and other trails. We strongly recommend that you follow the following requirements:
Carefully monitor the road and adequately respond to the appearance of other road users on it, whether they are pedestrians, cyclists, scooter riders or horses. Avoid conflict situations, reduce speed when overshooing or driving with other road users;
Do not violate the boundaries of private property, or fenced areas;

When overstaying or riding with riders on horseback, observe a sufficient distance to the horse. Remember, the horse is not accustomed to the sight of riders training on mechanical means and can be frightened. A frightened horse can cause serious injuries to both the rider and the object that frightened it, as well as other road users, including pedestrians;
3.12. Control your speed depending on road conditions and your experience. Do not allow acceleration to speeds at which you risk losing control of the trainee. This is especially true of descents and turns on the go. Remember that in the initial stages of training, until you have mastered the intuitive control of the trainee, a relatively safe speed is comparable to your walking step.
Pay special attention and caution to movement on inclined surfaces. Remember that the force of inertia is directly dependent on the mass of the rider and the speed developed. With a set of speeds, the force of inertia will complicate the management of the trainee. Therefore, moving on inclined surfaces, keep your hands on the levers and slow down with two brakes at the same time. Starting to descend on the surface with an angle exceeding 3%, take precautions, make sure that the brake system is working and stop the trainee completely at the very beginning of the descent to feel the work of the trainee and brake system. For braking, do not use the brakes separately, but only simultaneous pressing. Press and release the brakes smoothly. Remember that when braking to a complete stop on an inclined surface face down, as soon as you release the brakes, you will again go forward without making any effort. Therefore, gradually releasing the brakes, go down carefully. It is not recommended to descend on inclined surfaces at speeds above 3 km / h.
Remember that the trainee is controlled using the braking system, and the trainee with a rider who has gained speed above a calm foot step has a force of inertia that, when maneuvering, can lead to loss of control, fall and serious injuries.
For a safe turn when descending on an inclined surface, it is recommended to stop the trainee by pressing two brakes until it stops completely. After that, carefully release one brake, and continue to hold the one in which direction you want to turn. If you do not want to further accelerate the trainee, especially when descending on an inclined surface, try to step not forward, but backward. Stepping back will allow you to take a more comfortable position on the trainee and not give additional impetus to the movement.
increases with a set of speed increases the force of inertia.
3.13. We strongly recommend that you wear a helmet and gloves for any skating, and in conditions of high-speed skating - a set of additional body protection: elbow pads, patniks, spine protection (shell); For long autonomous trips outside the settlements, make sure that the trip is safe and that emergency communication with the rescue services is possible. Try not to go on long trips alone.

### 4. Basic rules of operation of the trainee

Attention! In order to avoid technical problems, you need to adhere to the following rules of operation of the trainee:
4.1. Keep your trainer clean. After riding in dusty, wet or dirty conditions, be sure to wash the trainee, paying special attention to the cleanliness of the chain, stars. Avoid directing the flow of water into the area of movable joints (auxiliary wheel columns, suspension hinges, wheel bushings).
4.2. After washing the trainee, as well as after riding in conditions of high humidity, be sure to wipe the chain dry, and then lubricate. As a lubricant, use specialized lubricants for bicycle chains. The lubricated chain should be kept alone for 5-10 minutes for the penetration of the samzka, and then wipe dry to avoid sticking dirt and dust. It is forbidden to use thick lubricants of all types (Litol, Citam, etc.) for lubrication of chains.
4.3. It is forbidden to immerse the trainee in water to a depth reaching the articulated suspension joints in the bearings of the hubs. If this happens, it is necessary to visit a specialized workshop as soon as possible, where a qualified mechanic will sort out the bushings for a new lubricant and remove the remaining water. It is also recommended after "bathing" the trainee to make sure that there is no water between the tire and the rim. The liquid can penetrate there through the spoked holes in the rims.
4.4. After 1-2 rides or no later than 14 days from the date of purchase of the trainee, you must contact the service center (or the official dealer who provides maintenance of the trainees) for test maintenance. In the future, it is recommended to carry out maintenance at least 1 time per year. Allowed natural backlash of articulations of pedals, handles, rods of connecting rods of speakers of auxiliary wheels and wheel hushes, backlash of connecting rods relative to the axis of the crankshaft, crunches and any other metal sounds when the bike moves. If in the sid of these reasons there was a drop in the efficiency of the brakes or also difficult management of the trainee, you should contact a specialized workshop to configure the trainee.
Further operation of the trainee with the above malfunctions can lead to the breakdown of other parts of the trainee, as well as injuries, injuries, etc. for the owner of the trainee.
4.5. Do not use the trainee for other purposes. Remember that the trainee is designed for individual training of medium intensity for one person. Do not use the trainee for downhill or in situations that may lead to its disbalance. Also remember that the use of the trainee in modes associated with increased loads on the nodes of the trainee, including in competitions or for the purpose of periodic training of inexperienced riders in the skills of riding on the trainee, deprives you of warranty support from the manufacturer.
4.6. Avoid mechanical blows to the trainee, its rolls over and falls. Modern frames made of aluminum alloys have a very small wall thickness and are subject to mechanical deformations. Attention: IT is STRICTLY forbidden to ride on the trainee, the frame, wheels, suspension levers, handles and controls of which have mechanical damage! Immediately take the trainee (without getting into it) to the service workshop to eliminate breakdowns.

### 5. Warranty Information only for Russian Federation

The trainee must be transferred to the buyer in a fully assembled form, with pre-sale preparation in the store (trade organization of the official dealer). In case of transfer to the buyer of the trainee in disassembled or partially disassembled form (including in the box), the manufacturer has the right to cancel the warranty. In case of non-compliance by the buyer with all the above rules of operation of the trainee, it is possible to refuse to provide warranty service.
The service life of the trainee is 5 years.
Terms of the guarantee. The warranty is provided only for new trainees and frames purchased from an authorized dealer's trade organization, as well as pre-sale training. The manufacturer (represented by the trade organization of the official dealer or directly), during the warranty period, provides replacement of components and parts of trainees in case of detection of defects of a manufacturing nature, subject to the rules of operation of the products and the absence of traces of mechanical damage on them for similar of proper quality. In the absence of the seller's stamp and the date of sale in the warranty card, quality claims are not accepted. 1. Trainees sold by an authorized dealer are not subject to warranty service in the following cases: a. normal (natural) wear of components and parts (applies to all movable elements of the trainee design: bearings, as well as gearshift mechanisms); b. consequences of an accident or traffic accident (including falling on the trainee); c. operation of the trainee in an unintended mode (as a cargo transport, as well as in any other way that does not correspond to the purpose of the product as a personal trainee); d. negligent treatment that led to a reduction in the life or failure of the trainee or its individual components; e. consequences of improper assembly, adjustment, repair or maintenance carried out independently or by persons who do not have authority to carry out these works. 2. Warranty obligations do not apply to cases of mechanical damage to the frame, chipping of the paintwork or deformations of other components of the trainee caused by mechanical action. 3. Warranty obligations do not apply to tires, cameras, wheel rims, shift cables and brake drives, brake pads, chains, grips, pedals, front and rear transmission stars, bearings, rear derailleur mounts, oil seals, dust motes, rubber seals, any plastic or rubber moving or rubbing parts, bolts and nuts, fork foot surfaces, brake and wheel mounting points, as these components are particularly susceptible to wear and require periodic replacement. The service life of all the above-mentioned parts and assemblies is determined by the conditions and intensity of use of the bike. Warranty obligations for trainees, frames and components do not apply to the consequences of using the trainee in winter, at temperatures below 0 ° C or in the rain, as well as full and partial immersion of components in mud. 4. Warranty obligations do not apply in cases of interference by the owner in the design of the trainee, replacement of components of his choice and modification of those installed by the manufacturer without the written consent of the manufacturer. 5. Warranty obligations are invalid if the trainee is used in stunt, sports competitions, ramp jumps, acrobatic exercises or other similar particularly harsh operating conditions, as well as during rental (rental, etc.). 6. The warranty is provided by the manufacturer, provided that the owner of the trainee will timely carry out maintenance of the bike at an official dealer or in specialized service workshops authorized to carry out the necessary maintenance work. 22 Warranty period of 1 (one) a year applies to the frames of the Ellic Raptor trainee and 6 (six) months for components (except as specified in paragraph 3 of this section and guarantees the absence of defects that occurred during the production process. In the presence of defects falling under the scope of this warranty, the manufacturer undertakes to replace or repair the frame and components at its own expense. The guarantee is provided in the presence of the original document confirming the fact of purchase (cash or product receipt). The warranty period is calculated from the date of purchase of the bike from an authorized representative of the manufacturer. Transportation costs are not covered by this warranty. 7. Warranty obligations apply only to the first owner, since initially the trainee is begged taking into account the biometric data of the buyer. The warranty card for the trainee is a personal document and is not subject to corrections and reissue to another person. 8. Covering the costs associated with the transportation of products is not included in the manufacturer's warranty obligations. The manufacturer's warranty representative at the points of sale is an official dealer or a person who has the status of an official dealer of Ellic trainees. 9. The manufacturer's warranty applies only to trainees sold by official dealers or persons (individual entrepreneurs) who have the status of an official dealer of Ellic trainees.

Attention! If the trainee does not match the biometric data of the buyer (see the dimensions of the trainee rider), the manufacturer is not responsible for causing harm to the health and life of the buyer. Trainees for customers over 190 cm tall and weighing more than 100 kg should be selected only with the help of specialist consultants in the stores of official dealers or persons with the status of official dealers of Ellic trainees, because not all models can withstand increased loads. ATTENTION: the buyer of the trainee is fully responsible for bodily injury, material damage or breakdown of the trainee (or its components) and causing any other damages in cases where the trainee was used in competitive events. The list of such includes any type of competitions, both having official status and not having it: cross-country racing, freestyle, ramp jumping, downhill (including biker cross and dual slalom), road racing, orienteering, multisport racing.THE WARRANTY PERIOD FOR COMPONENTS IS 6 MONTHS, FOR FRAMES 1 YEAR.

Manufacturer and manufacturer of the Ellic trainee is www.Ellic.bike LLC "Dvij.tech".
The list of works on pre-sale preparation:
1. Unpacking the trainee, checking the completeness.
2. Installation of wheels.
3. Installation of handles.
4. Pedal installation
5. Adjustment of the position of the brake levers.
6. Installation of front and rear reflectors.
7. Installation of chains.
8. Filling in the warranty card.
9. Checking the tightening moments of threaded connections in the main components of the trainee: handles - carriages - wheels - connecting rods - pedals
Note: The scope of work on the pre-sale preparation of a particular model of the trainee should correspond to its completeness.

Warranty card

Information about the trainee

Model / Decimal number __

Frame serial number __

Place of sale ___

Date of sale __

Seller's signature __

I have familiarized myself with the terms of warranty service, I have no claims for the selection of the size.

Name and Signature of the buyer __

Mark on pre-sale preparation

Filled in by the official representative of the manufacturer. The trainee is prepared for operation:

Company name __
Position __
Name __
signature __
date __

Register your trainee in the global registry www.Ellic.bike

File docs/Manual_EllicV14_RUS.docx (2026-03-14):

Прогулочный эллипс

Ellic (тренажер)

инструкция по эксплуатации

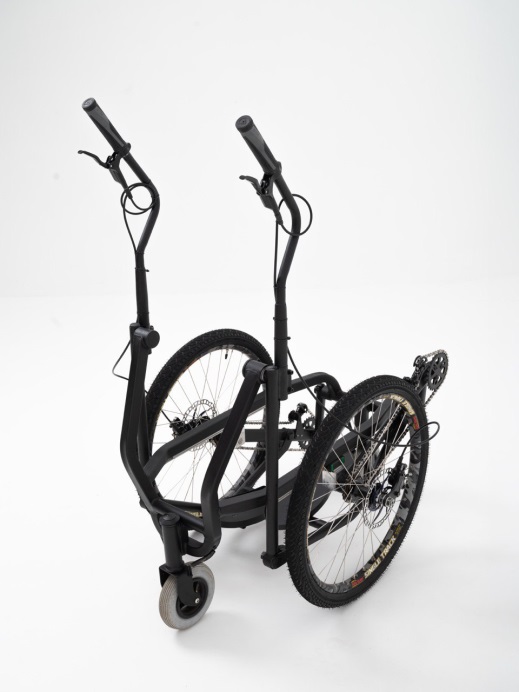
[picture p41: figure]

Уважаемый покупатель! Благодарим за выбор Ellic и поздравляем с покупкой современного тренажера для скандинавской ходьбы на колесах. Мы уверены, что при должном обслуживании и правильной эксплуатации Ваш тренажер долго будет служить Вам верой и правдой, и доставит множество приятных, увлекательных часов во время катания. Ваш тренажер обеспечит вам функциональность, комфорт и безопасность при соблюдении правил передвижения, изложенных в данном руководстве. Мы настоятельно просим Вас внимательно изучить данное руководство перед тем, как впервые приступить к тренировкам.

Содержание:

1. Общее устройство тренажера

2. Правила управления тренажером

3. Основные правила безопасности при эксплуатации тренажера

4. Основные правила по эксплуатации тренажера

5. Сведения о гарантии

Гарантийный талон

1. Общее устройство тренажера

Ellic представляет собой достаточно сложную конструкцию и, по сути, является следующим эволюционным шагом в развитии велосипеда, приближающее тренажер к колесному экзоскелету. При этом, значительное количество деталей тренажер заимствовал у велосипеда. В основе тренажера находится рама, на которую монтируются все остальные его элементы. Основные из них перечислены ниже.

Устройство содержит пространственную симметричную раму, имеющую боковые продольные направляющие, каретки, поступательно двигающиеся вперед-назад по продольным направляющим, два колеса, закрепленные своими осями на каретках и ручные рычаги, связанные с педалями и колесами.

Общий вид устройства Вид сбоку

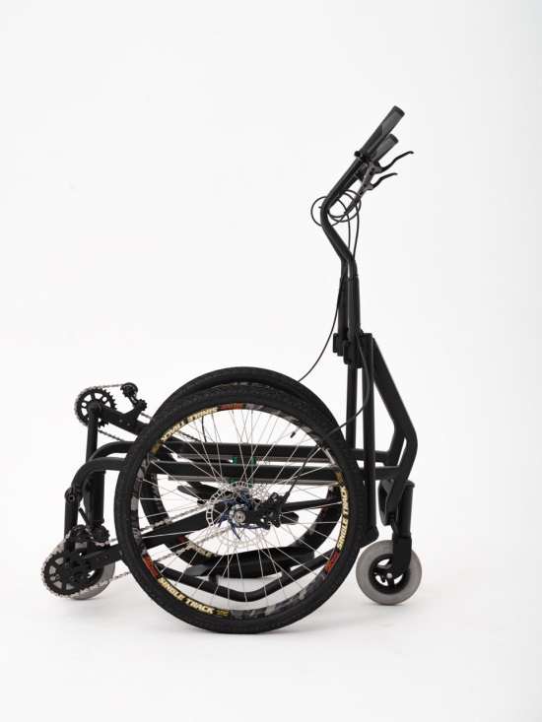
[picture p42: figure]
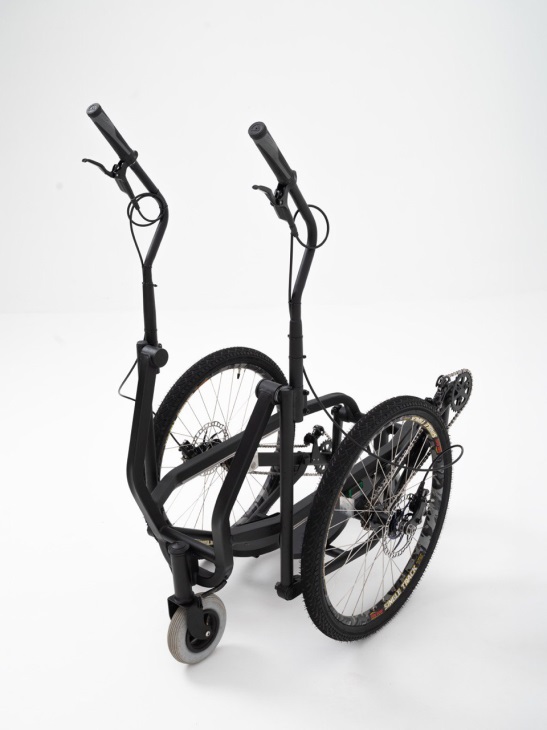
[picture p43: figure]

Вид со сложенными ручками Вид ручных рычагов с тормозами

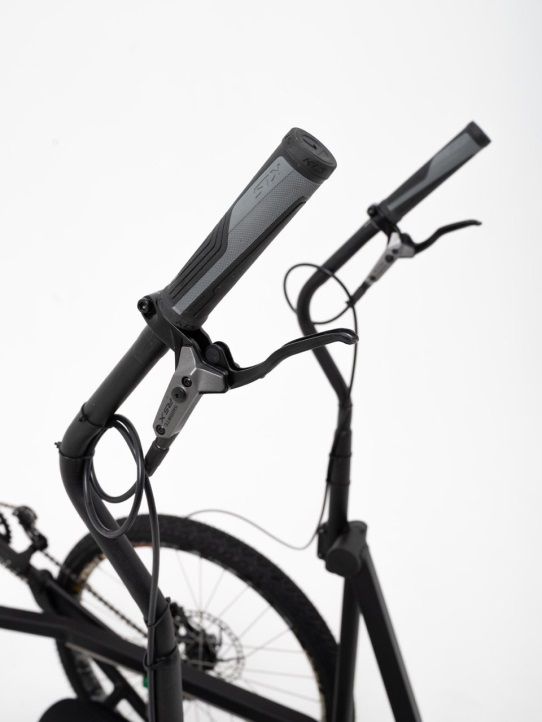
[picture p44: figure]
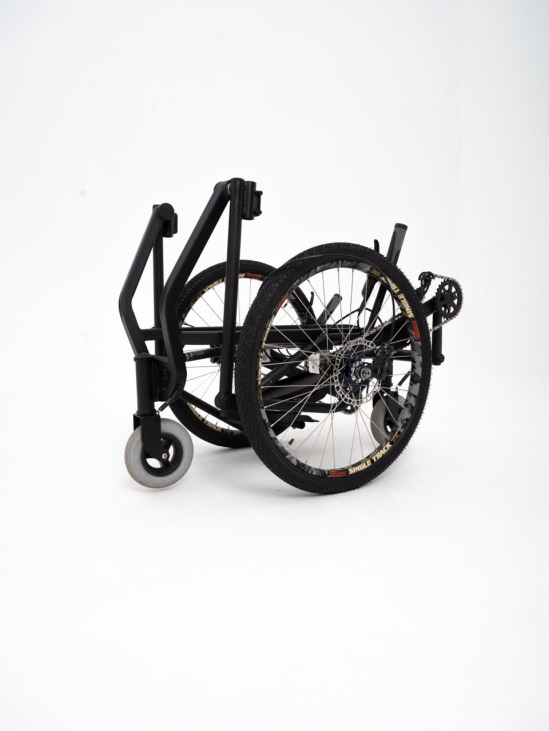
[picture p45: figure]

Габаритный рисунок

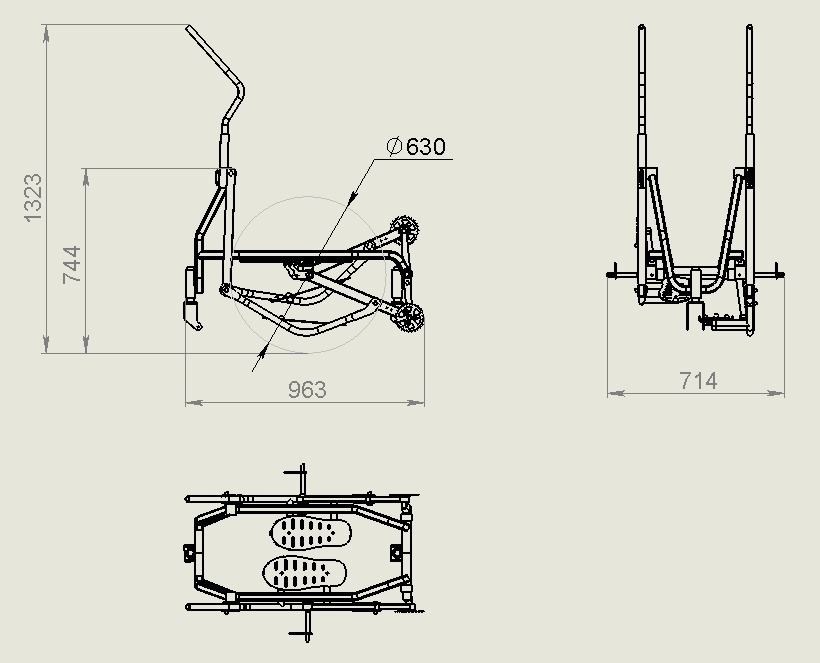
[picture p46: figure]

1. Ручной рычаг

3. Рама

4. Каретка

11. Педали

12. Колесо Каретка

2. Ось качания ручки

5,6. Звездочки Каретка

7. Шатуны

13. Ось вращения коленвала

14. Суппорт дискового тормоза

8. Тяга коленвала - каретки

Размеры наездника тренажера

Размер ноги: 35-46

Рост: 160 - 190

Вес: 60 - 100

На габаритном рисунке: движение вперед – налево; вращение коленвала – против часовой стрелки; положение колес – на одной оси (совмещены), положение ног - левая нога снизу, правая сверху; положение ручек – среднее положение хода;

Фиг. 3 – четыре такта перемещения устройства,

где:

1 – ручка (ручной рычаг);

2 – ось качания ручки;

3 – рама;

4 – каретка;

5, 6 – звездочки;

7 – шатун коленвала;

8 – тяга коленвала-каретки;

9 – цепь (не показана, одевается на звездочки 5,6 с каждой стороны);

10 – тяга педали;

11 – педаль;

12 – колесо (как правило 24 дюйма);

13 – ось вращения коленвала

14 – суппорт дискового тормоза.

Оси колес связаны с каретками и коленвалом. Ось вращения коленвала 13 расположена перпендикулярно продольным осям поступательного движения кареток 4. Коленвал имеет звездочки 6 на шатунах для передачи вращательного движения. Оси колес 12 также оснащены звездочками 5 с храповым механизмом. Коленвал связан с осью каждого колеса посредством тяги коленвала 8 и цепной передачи 9. Таким образом, вращательное движение коленвала преобразуется во вращение колес и их поступательное движение вперед-назад вдоль продольных направляющих.

Устройство также содержит ручные рычаги 1. Ручные рычаги 1 качаются на шарнирах, закрепленных на раме 3. Ось качания рычагов – 2.

К нижнему концу каждого ручного рычага 1 на шарнире крепится тяга педали 10. На другом конце тяги закрепляется педаль 11, на которую наездник встает ногой. Тяга педали 10 шарниром связана с тягой коленвала 8.

Наездник действует ручными рычагами 1 (руки перемещаются вперед-назад) и педалями 11 (двигаются по эллиптической траектории) имитируя движения ногами и руками, которые человек производит при ходьбе. Педали вращаются и вперед и назад. При вращении педалей вперед тренажер двигает колесами синхронно с ногами и едет вперед. При вращении педалей назад тренажер двигает колесами синхронно с ногами но не едет.

Для удобства тренажер оснащается вспомогательными колесами спереди и сзади.

Запрещается вносить изменения в конструкцию тренажера без письменного согласия производителя. Обслуживание тренажера рекомендуется проводить в специализированных или велосипедных мастерских.

2. Правила управления тренажером

Ellic чувственный тренажер, он дарит новые эмоции от гармоничной прогулки на колесах, а чтобы освоиться ходить на колесах нужно потренироваться.

Правило №1

Вход в Ellic сзади, а выход из Ellic спереди.

Чтобы войти в Ellic подойдите к нему сзади. Возьмитесь за ручные рычаги и зажмите тормоза. Перешагнув через раму встаньте на нижнюю педаль. Чтобы встать на Ellic сперва всегда наступайте на нижнюю педаль. На нижнюю педаль надо наступать, чтобы избежать прокручивания педалей назад. Вставая на тренажер сперва наступайте на нижнюю педаль.

Чтобы выйти из Ellic выходите всегда вперед. Остановитесь. Зажмите оба тормоза. Наступайте на перекладину под ногами и выходите вперед. Ellic спроектирован так, чтобы перед наездником не было предметов препятствующих выходу вперед.

Правило №2

Всегда стойте на педалях двумя ногами.

Не отрывайте подошвы от педалей. Совмещайте центр ноги с центром педали. Во избежание травм обувь, а тем более оголенные части ступни (ездить босиком не рекомендуется) не должны выступать за края педалей.

Правило №3

Ellic ходит ногами.

Как и в жизни - шагайте ногами и помогайте руками. Если двигать ногами неправильно поехать на руках не получится. Ловите баланс на ногах. Ellic шагает, чтобы повторять биомеханику человеческого тела. Колеса Ellic двигаются одновременно с ногами наездника. Этим обеспечивается баланс наездника в движении. Руки и ноги двигаются синхронно.

Правило №4

Если крутить педали назад, тогда колеса будут шагать вместе с ногами, но Ellic будет стоять на месте.

Правило №5

Самый легкий старт, когда на педаль давит передняя нога.

Стартовать из положения нога спереди легче, чем из положения нога сверху.

Правило №6

Чтобы ехать легко нужно найти баланс.

Не наваливайтесь на рычаги и не висите на них. Как всегда, баланс где-то посередине. Не переживайте, если найти его сразу не получается – вас подстрахуют вспомогательные колеса и баланс обязательно придет со временем. Чтобы поехать на Ellic вам придется расправиться и кататься с гордо поднятой головой.

Правило №7

Для торможения всегда зажимайте оба тормоза одновременно, чтобы избежать закручивания, заваливания и падений.

Правило №8

Сначала научитесь ездить прямо и только потом поворачивать.

Сначала научиться ездить прямо и только потом начинать учиться поворачивать на ходу. Не пугайтесь, что не получается сразу поворачивать. Сначала нужно немного привыкнуть к Ellic. Для этого просто поучитесь ездить прямо. И чем медленней тем лучше. Если вы сможете не торопиться, то лучше почувствуете свое тело и обучение пойдет проще. На первом занятии нужно научиться ездить прямо.

Правило №9

Не спешите и не торопитесь.

Для полноценной езды нужно чтобы ваше тело освоилось и реагировало само. Невозможно понять, как ездить на велосипеде, это надо почувствовать. Обычно для этого необходимо от одного до трех занятий. Особенно это касается поворотов и уклонов. Будьте предельно внимательны и собраны при управлении Ellic. Старайтесь почувствовать Ellic.

Правило №10

Шагать и катиться не одно и тоже.

Шагать это двигать ногами. Катиться это когда едут колеса.

Вы можете катиться и не шагать. Это значит, что колеса могут ехать, даже если вы не двигаете ногами. Например, накатом или вниз с горки.

А вот шагать (двигать ногами) вперед на месте вы уже не сможете. Ellic поедет вперед. Все как на обычном велосипеде.

Правило №11

Шагать и одновременно поворачивать нельзя.

Катиться и одновременно поворачивать можно. Чтобы поворачивать нужно катиться и не шагать. Это самое сложное правило. Но освоив его, вас уже будет не остановить.

Правило №12

Чем ближе совмещены колеса, тем легче поворот.

Правило №13

Ellic может повернуть на месте.

Правило №14

Ellic может ходить назад

Правило №15

Рычагами нельзя рулить, но можно подруливать.

Правило №16

Не прикладывайте чрезмерных усилий.

Ellic довольно просто двигается. Если вы прикладываете некомфортные для себя усилия, значит вы что то делаете не так. Немного расслабьтесь и подумайте, что вы делаете и какое из правил не соблюдаете.

Правило №17

Нельзя просто так взять и усвоить все правила сразу.

Как поворачивать?

Есть несколько способов поворачивать на Ellic. Здесь они перечислены по мере возрастания сложности.

1. Поворот на месте без движения.
2. Поворот в движении.
3. Подруливание ручными рычагами на ходу.
4. Подворачивание со старта со взводом педалей.

Рассмотрим способы поворота по порядку.

1. Поворот на месте без движения. Необходим для начинающих, так как позволяет выбираться из тупиковых ситуаций не выходя из Ellic. В последующем, когда вы освоите поворот в движении этот способ будет применяться только в редких случаях.

- Движением педалей назад поставьте ноги врозь так, чтобы сзади оказалась та нога в какую сторону вы хотите повернуть.

- Зажмите оба тормоза.

- Не отпуская тормозов сделайте шаг назад (прокрутите педали назад на половину полного оборота). Ellic повернется вокруг своей оси, а задняя нога переместиться вперед.

- Отпустите тормоза и осмотритесь.

- Если угол поворота недостаточен, то повторите цикл.

2. Поворот в движении.

- Катиться и одновременно поворачивать можно, а шагать и одновременно поворачивать нельзя. Это самое сложное правило. Но освоив его, вас уже будет не остановить.

- Лучше всего Ellic поворачивает, когда оси колес совмещены. Чем дальше друг от друга расставлены колеса, тем больше радиус поворота и ниже отзывчивость на управляющее воздействие. Контролируйте совмещение колес перед поворотом. Сначала это покажется сложным, но через несколько повторений вы доведете это до автоматизма.

Чтобы повернуть на ходу надо:

- Набрать небольшую скорость (можно побыстрее, но достаточно и небольшой);

- Перестать шагать;

- Совместить оси колес;

- Для поворота направо (налево) нажать на правый (левый) тормоз.

- Контролируйте скорость, помните, что чем ниже скорость тем безопаснее маневр. Обучайтесь и совершайте повороты на безопасной скорости вашей неспешной ходьбы .

3. Подруливание ручными рычагами на ходу.

Чтобы сместить курс движения тренажера на ходу вправо нужно с дополнительным усилием потянуть на себя правый рычаг.

Чтобы сместить курс движения тренажера на ходу влево нужно с дополнительным усилием потянуть на себя левый рычаг.

- Не отрывайте подошв от педалей и не переносите вес всего тела на верхнюю педаль и дальний рычаг. Эти действия увеличивают высоту центра тяжести Ellic с наездником и при неопытном управлении могут привести к опрокидыванию.

- Не рекомендуется использовать этот прием для поворотов на первом занятии.

4. Подворачивание со старта со взводом педалей.

- Для поворота налево поместите рычаг левой руки вперед, а правый назад.

- С приложением усилия потяните левый рычаг назад, а правый с усилием толкайте вперед.

- Одновременно создавайте добавленное усилие на передней педали.

- Ищите положение, в котором рычагами и педалями создается максимальный крутящий момент. Обычно такой момент создается, когда верхняя педаль уже прошла крайнюю верхнюю точку но еще не дошла до крайней передней точки.

- Проходя отрезки максимального момента вращением педалей назад возвращайте рычаги в положение максимального момента.

- Не отрывайте подошв от педалей и не переносите вес всего тела на верхнюю педаль и дальний рычаг. Эти действия увеличивают высоту центра тяжести Ellic с наездником и при неопытном управлении могут привести к опрокидыванию.

- Не рекомендуется использовать этот прием для поворотов на первом занятии.

Как шагать назад?

Ellic может шагать назад. Для этого надо крутить педали (шагать) назад и попеременно зажимать то левый то правый тормоз, как-бы цепляясь задней ногой за дорогу и отталкиваться ей вперед.

Пройдем по пунктам:

1. Встаем так, чтобы правая нога оказалась сзади. Установить такое положение можно на месте прокручивая педали назад.
2. Зажимаем правый тормоз. Не отпуская тормоз делаем шаг назад (прокручиваем педали назад на половину полного оборота), до тех пор, пока правая нога не окажется впереди.
3. Отпускаем тормоз.
4. Ellic делает шаг назад и сзади оказывается левая нога.

Тоже самое зеркально делаем для другой ноги.

1. Зажимаем левый тормоз. Не отпуская тормоз делаем шаг назад (прокручиваем педали назад на половину полного оборота), до тех пор, пока левая нога не окажется впереди.
2. Отпускаем тормоз.
3. Ellic делает шаг назад и сзади оказывается правая нога.

Повторите столько раз, сколько нужно.

Упражнения для обучения

1. Встаньте на тренажер (нижнюю педаль?)

поочередно опирайтесь на переднее и заднее вспомогательные колесики. Повторите 10 раз.

Прокрутите педали назад. Чувствуете, как колеса следуют за ногами?

2. Как и в ходьбе у вас есть 4 такта движения. Для простоты - выберите любимую ногу.

Медленно крутите педали назад. Обратите внимание на такты

Любимая нога внизу

Любимая нога спереди

Любимая нога сверху

Любимая нога сзади.

Мы близки к тому, чтобы попробовать прокатиться. Но сначала попробуйте покачаться вперед назад в каждом разных положениях. Спинку ровно, балансируем ногами. Вы готовы ехать если получается отпускать руки и стоять ровно на ногах.

3. Стартуем.

Для этого работаем ногами. 90% энергии движу дают ноги. Начать ехать лучше оперевшись на переднее вспомогательное колесико. Если тронуться не получается - остановитесь. Подумайте что делаете неправильно. Не прекращая контакта переднего вспомогательного колеса с землей прокрутите педали назад. Останавливайте вращение в разных положениях и попробуйте поймать момент старта.

Не пытайтесь вырвать рычаги. Не висите на рычагах. Приложение излишних усилий к рычагам смещает баланс и поворачивает Ellic. Ellic как ходьба - движется ногами.

Если вы прикладываете усилие, а Ellic не отзывается и не едет, значит вы что то делаете не так.

Чрезмерных усилий прикладывать не надо.

Если вы чувствуете, что прикладываете адские усилия, - остановитесь.

Подумайте, что вы делаете.

Чтобы обнулить впечатления - прокрутите педали назад.

4. Упражнения для прямолинейного катания. Повторите каждое упражнение 3 раза.

Сделайте два шага, перестаньте шагать и продолжайте катиться.

Сделайте два шага, поставьте правую ногу вниз, перестаньте шагать и продолжайте катиться.

Сделайте два шага, поставьте левую ногу вниз, перестаньте шагать и продолжайте катиться.

Сделайте два шага, перестаньте шагать, продолжайте катиться, не останавливаясь прокрутите педали назад.

Внимание!

Не разгоняйтесь пока не почувствуете, как управляется тренажер. Избегайте резких торможений и поворотов. На первых занятиях не рекомендуется движение вниз с горок. Помните, что на Ellic вы передвигаетесь верхом и несете ответственность не только за себя но и за окружающих.

Как регулировать тормозные колодки?

На вашем тренажере установлены дисковые механические тормоза, время от времени необходимо проверять положение тормозных колодок относительно тормозного диска.

Дисковые механические тормоза имеют одну неподвижную колодку и одну подвижную, приводимую тормозным тросом от тормозной ручки. Настройке положения подвергаются как обе колодки, так и корпус механического дискового тормоза. Начать следует с регулировки последнего.

1. Ослабьте крепежные болты, крепящие корпус тормоза к каретке;

2. Вставьте корпус тормоза так, чтобы тормозной диск проходил строго по центру прорези в корпусе тормоза;

3. Затяните крепежные болты, не допуская перекоса корпуса тормоза;

4. С помощью регулировки на внутренней стороне корпуса тормоза выставьте неподвижную тормозную колодку на минимальное расстояние до тормозного диска, не допуская, однако, ее касания диском.

5. С помощью регулировки на внешней стороне корпуса тормоза аналогичным образом выставьте подвижную тормозную колодку так, чтобы зазор составлял не более 1 мм.

6. Проверьте работу тормоза. Полное прижатие колодок друг к другу (через тормозной диск)

7. Отрегулируйте холостой ход ручки с помощью вращающегося винта на ней.

Правильно отрегулированный механический дисковый тормоз должен уверенно останавливать велосипед при нажатии на тормозную ручку и в то же время непрепятствовать вращению тормозного диска при отпущенной тормозной ручке. Допустимо легкое касание диска колодками, если это не вызывает ощутимого торможения колеса. Гидравлические тормоза санной выше с поправкой на тип привода тормоза и то, что большинство гидравлических дисковых тормозов имеют две самоподводящиеся подвижные колодки. Тонкую настройку положения корпуса тормоза и соответственно тормозных колодок на гидравлических тормозах, а также прокачку тормозов лучше доверить квалифицированному механику.

4. Основные правила безопасности при эксплуатации тренажера

3.1. Катание на тренажере связано с определенным риском и повышенной опасностью. Чтобы свести риск к минимуму, убедительно просим Вас придерживаться Правил дорожного движения, а также выполнять элементарные требования безопасности, связанные со спецификой движения на тренажере. При этом следует понимать, что не существует таких мер предосторожности, при помощи которых можно было устранить любой риск.

3.2. Мы настоятельно рекомендуем использовать велосипедные перчатки со специальной подкладкой на ладони. Они защитят ваши ладони от травм при случайном падении и, кроме того, обеспечат более надежный хват рычагов и снизят вибрации, проходящие от грунта через детали тренажера к ручным рычагам.

3.3. Не катайтесь на тренажере, прослушивая музыку или другие аудиосигналы через наушники, так как в этом случае Вы не сможете оперативно отслеживать ситуацию вокруг себя на слух. Выезд на тренажере на дороги общего пользования не допускается.

3.4. Убедитесь в том, что тормоза тренажера работают эффективно, и всегда поддерживайте Ваш тренажер в исправном техническом состоянии. При торможении контролируйте усилие торможения, не допуская избыточного торможения. Старайтесь тормозить с одинаковой интенсивностью обоими тормозами.

3.5. Следите за выбоинами, канавами и прочими опасными предметами на дороге. В случае внезапного обнаружения препятствия на дороге ни в коем случае не объезжайте его слева, чтобы не создавать помех участникам движения. Помните: велосипед, скутер или автомобиль, приближающийся сзади, чаще всего не способен менять направление движения достаточно быстро, чтобы избежать столкновения с резко сместившимся в сторону впередиидущим объектом.

3.6. При катании на тренажере надевайте яркую, заметную одежду. Это сделает Вас намного лучше видимым другими участниками движения. В большинстве случаев водитель, загодя заметив впереди препятствие, предпримет все возможное чтобы обогнать его наиболее безопасно. Одежда не должна стеснять движений, при этом она не должна быть очень просторной во избежание попадания или заматывания ее частей в движущихся частях тренажера: звездочках, шатунах, спицах, тягах, каретках. Мы советуем покупать специализированную одежду для тренировок в соответствующих магазинах.

3.7. Категорически запрещено демонтировать с велосипедов световозвращатели (катафоты). Тренажер должен иметь передний световозвращатель белого цвета, задний - красного и боковые - желтого.

3.8. Перевозите тренажер через дороги общего пользования, железнодорожные или трамвайные пути только спешившись и под прямым углом.

3.9. Катание на тренажере ночью или в условиях ограниченной видимости (в темное время суток, в туман, в дождь, в сумерках) чрезвычайно опасно и предъявляет дополнительные требования к наезднику. Рекомендуем воздержаться от катания в таких условиях. Также обращаем внимание на то, что катание в темное время суток без дополнительного светового оборудования (фонари, маячки) особенно опасно, а в большинстве европейских стран запрещено законодательно. Если Вы используете светотехнику с питанием от аккумуляторов, то перед поездкой убедитесь в ее исправности, а также в том, что батареи (аккумуляторы) полностью заряжены.

ВНИМАНИЕ! Риск травм и несчастных случаев возрастает при неправильном использовании тренажера, а именно:

- прыжки на тренажере;

- езда по веткам, корням деревьев, мусору или другим препятствиям;

- выполнение трюков на тренажере;

- быстрая езда, участие в гонках или скоростном спуске (даунхилл);

- езда необычным способом;

- экстренное торможение, в том числе одним тормозом;

Все вышеперечисленное - примеры неправильного использования, которое увеличивает нагрузку на все детали тренажера. Высокая нагрузка может вызвать поломку, что может увеличить риск получения травм и увечий. Для уменьшения риска травм и несчастных случаев не допускайте вышеперечисленных видов эксплуатации.

3.10. Катание в дождливую погоду или в условиях повышенной влажности

Помните, что в сырую погоду тормоза теряют часть своей эффективности, поэтому всегда учитывайте это при езде. Также следует помнить, что мокрая дорога более скользкая, чем сухая, поэтому при езде по влажной или мокрой дороге контролируйте свою скорость, избегайте резких маневров и внезапных торможений. Особую внимательность проявляйте при пересечении железнодорожных или трамвайных путей, дорог общего пользования, металлических поверхностей, дорожной разметки, которая в мокрую погоду особенно скользкая.

3.11. Катание по пересеченной местности, а также в местах отдыха

Рост популярности индивидуальных средств транспорта вызывает дополнительные требования к наездникам, катающимся на территории парков, зон отдыха, лыжных и прочих трасс. Мы настоятельно рекомендуем следовать следующим требованиям:

Внимательно следите за дорогой и адекватно реагируйте на появление на ней других участников движения, будь то пешеходы, велосипедисты, наездники на скутерах или на лошадях. Избегайте конфликтных ситуаций, снижайте скорость при обгоне или разъезде с другими участниками движения;

Не нарушайте границ частной собственности, или огражденных территорий;

При обгоне или разъезде с наездниками на лошадях соблюдайте достаточное расстояние до лошади. Помните, лошадь не приучена к виду наездников, тренирующихся на механических средствах и может пугаться. Испуганная лошадь способна причинить тяжелые травмы, как наезднику, так и испугавшему ее объекту, а также другим участникам движения, включая пешеходов;

3.12. Контролируйте вашу скорость движения в зависимости от дорожных условий и вашего опыта. Не допускайте разгона до скоростей, при которых вы рискуете потерять управление тренажером. Особенно это касается спусков и поворотов на ходу. Помните, что на начальных этапах тренировок, пока вы не освоили интуитивное управление тренажером относительно безопасной является скорость сопоставимая с вашим пешим шагом.

Особенное внимание и осторожность уделяйте движению по наклонным поверхностям. Помните, что сила инерции находится в прямой зависимости от массы наездника и развиваемой скорости. С набором скорости сила инерции будет усложнять управление тренажером. Поэтому, двигаясь по наклонным поверхностям удерживайте руки на рычагах и притормаживайте двумя тормозами одновременно. Начиная спускаться по поверхности с углом, превышающим 3% предпримите меры предосторожности, убедитесь в работе тормозной системы и остановите тренажер полностью в самом начале спуска, чтобы почувствовать работу тренажера и тормозной системы. Для торможения не используйте тормоза по отдельности, а только одновременное нажатие. Нажимайте и отпускайте тормоза плавно. Помните, что при торможении до полной остановки на наклонной поверхности лицом в сторону спуска, как только отпустите тормоза вы снова поедете вперед, не прикладывая никаких усилий.

Поэтому, постепенно отпуская тормоза спускайтесь осторожно. Не рекомендуется спускаться по наклонным поверхностям на скорости выше 3 км/ч.

Помните, что управление тренажером производится при помощи тормозной системы, а тренажер с наездником набравший скорость выше спокойного пешего шага обладает силой инерции которая при маневрировании может привести к потере управления, падению и тяжелым травмам.

Для безопасного поворота при спуске по наклонной поверхности рекомендуется остановить тренажер нажатием двух тормозов до полной остановки. После этого осторожно отпускать один тормоз, и продолжать удерживать тот, в какую сторону вы хотите повернуть. Если вы не хотите дополнительно разгонять тренажер, особенно при спуске по наклонной поверхности, старайтесь шагать не вперед, а назад. Шагание назад позволит вам занять более удобное положение на тренажере и не придавать дополнительный импульс движению.

увеличивается с набором скорости увеличивается сила инерции.

3.13. Категорически рекомендуем при любом катании обязательно надевать шлем и перчатки, а в условиях скоростного катания - комплект дополнительной защиты тела: налокотники, наколенники, защиту позвоночника (панцирь);

При длительных автономных выездах за пределы поселений убедитесь в безопасности поездки и возможности экстренной связи со службами спасения. Старайтесь не выезжать в длительные поездки в одиночку.

4. Основные правила эксплуатации тренажера

Внимание! Во избежание проблем технического характера Вам необходимо придерживаться следующих правил эксплуатации тренажера:

4.1. Держите свой тренажер в чистоте. После катания в пыльных, влажных или грязных условиях обязательно мойте тренажер, уделяя особое внимание чистоте цепи, звезд. Избегайте направлять поток воды в зону подвижных соединений (колонки вспомогательных колес, шарниры подвески, колесные втулки).

4.2. После мойки тренажера, а также после катания в условиях повышенной влажности, в обязательном порядке вытирайте цепь насухо, а потом смазывайте. В качестве смазки используйте специализированные смазки для велосипедных цепей. Смазанную цепь следует выдержать в покое 5-10 минут для проникновения самзки, а затем вытереть насухо для избежания налипания грязи и пыли. Запрещается использовать для смазки цепей густые смазки всех видов (Литол, Цитам, и т.п.).

4.3. Запрещается погружать тренажер в воду на глубину достигающую шарнирных соединений подвески в подшипники втулок. Если же таковое случилось, необходимо в кратчайшие сроки посетить специализированную мастерскую, где квалифицированный механик переберет втулки на новую смазку и удалит остатки воды. Также рекомендуем после "купания" тренажера убедиться в отсутствии воды между покрышкой и ободом. Жидкость может проникать туда через спицевые отверстия в ободьях.

4.4. После 1-2 катаний либо не позднее 14 дней с момента покупки тренажера необходимо обратиться в сервисный центр (либо к официальному дилеру, осуществляющему сервисное обслуживание тренажеров) для проведения контрольного технического обслуживания. В дальнейшем, рекомендуется проводить техническое обслуживание не реже, чем 1 раз в год. Допускается естественный люфт сочленений педалей, ручек, тяг шатунов колонок вспомогательных колес и колесных втулок, люфт шатунов относительно оси коленвала, хрусты и любые другие металлические звуки при движении велосипеда. В случае если в сиду указанных причин произошло падение эффективности тормозов или также затруднительное управление тренажером следует обратиться в специализированную мастерскую для проведения настройки тренажера.

Дальнейшая эксплуатация тренажера с вышеуказанными неисправностями может привести к поломке других деталей тренажера, а также получению травм, увечий и т.п. для владельца тренажера.

4.5. Не используйте тренажер не по назначению. Помните, что тренажер предназначен для индивидуальных тренировок средней интенсивности для одного человека. Не используйте тренажер для скоростного спуска или в ситуациях, которые могут привести к его выводу из равновесия. Также помните, что использование тренажера в режимах, связанных с повышенными нагрузками на узлы тренажера, в том числе в соревнованиях или в целях периодического обучения неопытных наездников навыкам езды на тренажере, лишает вас гарантийной поддержки производителя.

4.6. Избегайте механических ударов по тренажеру, его переворачиваний и падений. Современные рамы из алюминиевых сплавов имеют очень малую толщину стенок и подвержены механическим деформациям. Внимание: КАТЕГОРИЧЕСКИ запрещено катание на тренажере, рама, колеса, рычаги подвески, ручки и органы управления которого имеют механические повреждения! Немедленно отвезите тренажер (не вставая в него) в сервисную мастерскую для устранения поломок.

5. Сведения о гарантии

Тренажер должен быть передан покупателю в полностью собранном виде, с проведенной предпродажной подготовкой в магазине (торговой организации официального дилера). В случае передачи покупателю тренажера в разобранном или частично разобранном виде (в том числе в коробке), изготовитель имеет право аннулировать гарантию. В случае НЕСОБЛЮДЕНИЯ покупателем всех вышеуказанных правил эксплуатации тренажера, возможен отказ в предоставлении гарантийного обслуживания.

Срок службы тренажера составляет 5 лет.

Условия предоставления гарантии. Гарантия предоставляется только на новые тренажеры и рамы, приобретенные в торговой организации официального дилера, а также прошедшие предпродажную подготовку. Изготовитель (в лице торговой организации официального дилера или непосредственно) в течение гарантийного срока обеспечивает замену узлов и деталей тренажеров в случае обнаружения дефектов производственного характера при соблюдении правил эксплуатации продукции и отсутствии на них следов механического повреждения на аналогичные надлежащего качества. При отсутствии в гарантийном талоне штампа продавца и даты продажи претензии по качеству не принимаются. 1. Проданные официальным дилером тренажеры не подлежат гарантийному обслуживанию в следующих случаях: a. нормальный (естественный) износ узлов и деталей (относится ко всем подвижным элементам конструкции тренажера: подшипники, а также механизмы переключателей передач); b. последствия аварии или дорожно-транспортного происшествия (включая падение на тренажера); c. эксплуатация тренажера в непредусмотренном режиме (в качестве грузового транспорта, а также любым другим образом, не соответствующим предназначению изделию как персонального тренажера); d. пренебрежительное обращение, приведшее к сокращению ресурса или выходу из строя тренажера или отдельных его компонентов; e. последствия неправильной сборки, регулировки, ремонта или техобслуживания проведенного самостоятельно или лицами, не имеющими полномочий на проведение данных работ. 2. Гарантийные обязательства не распространяются на случаи механического повреждения рамы, сколов лакокрасочного покрытия или деформаций иных компонентов тренажера, вызванных механическим воздействием. 3. Гарантийные обязательства не распространяются на покрышки, камеры, колесные ободья, тросы переключения и тормозов приводы, тормозные колодки, цепи, грипсы, педали, передние и задние звезды трансмиссии, подшипники, крепления заднего переключателя, сальники, пылинки, резиновые уплотнители, любые пластиковые или резиновые движущиеся или трущиеся части, болты и гайки, поверхность ног вилок, места крепления тормозов и колес, так как эти узлы особенно подвержены износу, требуют периодической замены. Срок службы всех вышеперечисленных деталей и узлов определяется условиями и интенсивностью использования велосипеда. Гарантийные обязательства на тренажеры, рамы и компоненты не распространяются на последствия использования тренажера в зимний период, при температуре ниже 0°С или под дождем, равно как и полное и частичное погружение компонентов в грязь. 4. Гарантийные обязательства не распространяются в случаях вмешательства владельцем в конструкцию тренажера, замены компонентов по своему выбору и модификации установленных производителем без письменного согласования производителем. 5. Гарантийные обязательства недействительны, если тренажер используется в трюковых, спортивных соревнованиях, прыжках в рампе, акробатических упражнениях или иных подобных особо жестких условиях эксплуатации, а также при эксплуатации в прокате (сдаче в аренду и т.п.). 6. Гарантия, предоставляется производителем при условии, что владелец тренажера будет своевременно проводить техническое обслуживание велосипеда у официального дилера или в специализированных сервисных мастерских, имеющих полномочия для проведения необходимых сервисных работ. 22 Гарантия сроком 1 (один) год распространяется на рамы тренажера Ellic Raptor и 6 (шесть) месяцев на комплектующие (за исключением указанных в п. 3 настоящего раздела и гарантирует отсутствие дефектов, возникших в процессе производства. При наличии дефектов, попадающих под действие настоящей гарантии, производитель обязуется за свой счет произвести замену или ремонт рамы и комплектующих. Гарантия предоставляется при наличии оригинала документа, подтверждающего факт покупки (кассовый или товарный чек). Срок действия гарантии исчисляется с даты покупки велосипеда у уполномоченного представителя изготовителя. Транспортные расходы настоящей гарантией не покрываются. 7. Гарантийные обязательства распространяются только на первого владельца, так как изначально тренажер побирается с учетом биометрических данных покупателя. Гарантийный талон на тренажер является именным документом и не подлежит исправлениям и переоформлению на другое лицо. 8. Покрытие расходов, связанных с транспортировкой изделий, в гарантийные обязательства фирмы-изготовителя не входит. Гарантийным представителем изготовителя в местах продаж является официальный дилер или лицо, имеющее статус официального дилера тренажеров Ellic. 9. Гарантия производителя распространяется только на тренажеры, проданные официальными дилерами, или лицами (индивидуальными предпринимателями), имеющими статус официального дилера тренажеров Ellic.

Внимание! В случае несоответствия тренажера биометрическим данным покупателя (см размеры наездника тренажера), изготовитель не несет ответственности за причинение вреда здоровью и жизни покупателя. Тренажеры для покупателей ростом свыше 190 см и весом более 100кг должны подбираться только с помощью специалистов-консультантов в магазинах официальных дилеров или лиц, имеющих статус официальных дилеров тренажеров Ellic т.к. повышенные нагрузки выдерживают не все модели. ВНИМАНИЕ: покупатель тренажера несет всю ответственность за телесные повреждения, материальный урон или поломку тренажера (или его узлов) и причинение любых других убытков в тех случаях, когда тренажер использовался в состязательных мероприятиях. Список таковых включает в себя любые виды соревнований, как имеющих официальный статус, так и не имеющих его: гонки кросс-кантри, фристайл, прыжки в рампе, скоростной спуск (включая байкер-кросс и дуал-слалом), шоссейные гонки, спортивное ориентирование, мультиспортивные гонки.

ГАРАНТИЙНЫЙ СРОК НА КОМПЛЕКТУЮЩИЕ СОСТАВЛЯЕТ 6 МЕСЯЦЕВ, НА РАМЫ 1 ГОД.

Производителем и изготовителем тренажера Ellic является www.Ellic.bike (http://www.jarri.bike) ООО «Движ.тех».

Перечень работ по предпродажной подготовке:

1. Распаковка тренажера, проверка комплектности.

2. Установка колес.

3. Установка ручек.

4. Установка педалей

5. Регулировка положения тормозных рычагов.

6. Установка переднего и заднего световозвращателей.

7. Установка цепей.

8. Заполение гарантийного талона.

9. Проверка моментов затяжки резьбовых соединений в основных узлах тренажера: ручки – каретки - колеса - шатуны - педали

Примечание: Объем работ по предпродажной подготовке конкретной модели тренажера должен соответствовать его комплектности.

Гарантийный талон

Сведения о тренажере

Модель / Децимальный номер ______________________ / ______________________

Серийный номер рамы ________________________

Место продажи ________________________

Дата продажи ________________________

Подпись продавца ________________________

С условиями гарантийного обслуживания ознакомлен, претензий по подбору размера не имею.

ФИО и Подпись покупателя ________________________ ________________________

Отметка о проведении предпродажной подготовки

Заполняется официальным представтелем производителя. Тренажер к эксплуатаци подготовлен:

Название компании ________________________

Должность ________________________

ФИО ________________________

подпись ________________________

дата _____________________________ ________________________________________________

Зарегистрируй свой тренажер в глобальном реестре www.Ellic.bike

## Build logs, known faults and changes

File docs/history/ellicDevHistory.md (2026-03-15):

# Ellic Development History

This document describes the historical development of the Ellic locomotion platform.

The project has gone through many prototype generations exploring different mechanical solutions, drive systems, and ergonomics.

The table below lists the major development stages.

---

## Prototype Evolution

| # | Prototype | Cost (k RUB) | Description |
|---|---|---|---|
|1|Scissors|200|First experimental prototype|
|2|Combine|600|Developed with Bauman Moscow State Technical University. No drive system yet|
|3|Ladya|750|New kinematic approach. Belt-linked pulley system introduced|
|4|Scooter|700|Return to lever drive concept|
|5|Shvedka|650|Ergonomic experiments with handle and crank geometry|
|6|Motor Control System v1|570|Development of motor controllers, PCBs, firmware, gyroscope control|
|7|Lebed|870|Frame stiffness improvements|
|8|Kareta|650|Frame geometry experiments for stability|
|9|Mini Kareta|550|Frame optimization for transport|
|10|Mini Kareta Front Drive|350|Foot trajectory experiments|
|11|Blue Goose|700|Reduced dimensions and increased strength|
|12|Orange Goose|900|Three-motor configuration experiments|
|13|Kid|300|Toy educational version using aluminum profiles|
|14|Black Raptor|960|Simplified frame and cantilever wheel mounting|
|15|Motor Raptor|570|Compact motorized version|
|16|Motor Control System v2|760|Redesigned control electronics|
|17|White Raptor|700|Simplified design and improved manufacturability|
|18|Pilot Support System (Blue)|100|Support system for riders with disabilities|
|19|Remote Support System (Orange)|300|Tests with children with cerebral palsy|
|20|Gear Geometry Stabilization|70|Torque stabilization during walking cycles|
|21|Bottom Bracket Motor Integration|450|Mechanical integration of pedal motor|
|22|Three Motor Integration|300|Software and electrical integration|
|23|Documentation Development|30|User manual and training materials|
|24|Innovation Fund Grant|—|2M RUB grant received|
|25|Production Documentation|700|Manufacturing documentation prepared|
|26|3 Production Prototypes|1000|Manufacturing of three machines|
|27|Scientific Technical Report|300|Final technical documentation|

---

## Direct Development Investment

**Total direct engineering investment**

≈ **14,030,000 RUB**

---

## Additional Activities

| Activity | Cost (k RUB) | Description |
|---|---|---|
|Fitness Exhibition|40|Public presentation|
|Integration Expo 2024|40|Start of partnership with Grossko|
|Integration Expo 2025|40|Continuation of public demonstrations|
|Robofinist Exhibition|150|3-day continuous operation tests|
|Grant Applications|200|Preparation of innovation grants|
|Social Media Content|600|More than 20M views across platforms|
|Websites|200|Project websites|
|Patents|300|Several patents filed and maintained|
|Human Trials|620|Testing at rehabilitation center|

---

## Additional Investment

**≈ 2,190,000 RUB**

---

## Founder Work

Founder contribution:

- development since **September 2019**
- approximately **0.25 full-time equivalent**

Estimated labor contribution:

≈ **3,600,000 RUB**

---

## Total Estimated Investment

Engineering + ecosystem development:

≈ **19,820,000 RUB**

---

This history illustrates the long experimental path behind the current Ellic prototype.

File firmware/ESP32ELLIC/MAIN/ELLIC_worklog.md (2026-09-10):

# ELLIC — рабочий журнал (worklog)

Этот документ — рабочий, не нормативный. Здесь фиксируются открытые вопросы, история их
исследования и план действий. Нормативное поведение системы описано в `ELLIC_spec.md` —
если пункт здесь противоречит спецификации, спецификация приоритетна, а этот пункт нужно
явно закрыть (перенести решение в спецификацию) или отклонить.

---

## 0. Важный контекст: смена протокола UART → CAN

Часть более ранних обсуждений и предыдущей отладки велась для архитектуры на **UART**
(модуль `ODriveUART`, ASCII-протокол ODrive, пины TX/RX на GPIO5 и др.). Актуальные
спецификация и код (`ODriveCAN.h/.cpp`) уже полностью описывают **CAN Simple** архитектуру
(TWAI, GPIO16/17, `Config.h` без UART-пинов ODrive вообще). Это значит:

- Все пункты ниже, унаследованные из UART-эпохи, помечены **[UART, требует проверки]** —
  нужно явно решить, актуальны ли они после перехода на CAN, или сняты сами собой.
- Конфигурация ODrive теперь **не отправляется с ESP32 в runtime вообще** (ни ASCII, ни
  CAN-конфигурация) — она должна быть заранее сохранена в самом ODrive через `odrivetool`
  по USB (раздел 10.2 спецификации). Раньше упомянутый баг с `InputMode.PASSTHROUGH` →
  числовое значение `5` тоже относится к этому пути конфигурации через `odrivetool`, а не к
  рантайм-коду ESP32 — эта конфигурация актуальна и переносится в раздел 2 этого документа.
- Раздел 11 спецификации (`loop()`) в текущем тексте не упоминает `odriveCAN.update()`, хотя
  он есть в `main.cpp`, и упоминает `updateConfigure()`, которого в `main.cpp` нет. Это
  расхождение зафиксировано как открытый пункт ниже (см. 1.6).

---

## 1. Открытые вопросы и задачи

### 1.1. Калибровка зон поворота (TURN_ZONE)

Зона поворота срабатывает только в определённых угловых диапазонах (±10° вокруг 0°/180°),
физически эти зоны не совпадают с ожидаемыми положениями вала. Требуется калибровка
привязки `rawAngle` AS5600 к физическим точкам механизма.

- [ ] Определить фактическое физическое положение вала в моменты, когда ожидается 0° и 180°.
- [ ] Проверить, нет ли смещения нуля AS5600 (магнит/установка датчика) или программной
      привязки в `Encoder`/`Config.h`.
- [ ] Решить: компенсировать смещение константой (например, `ANGLE_OFFSET_DEG`) или
      физической перестановкой датчика — и внести выбранный вариант в спецификацию.

### 1.2. Отказ поворота при нажатии тормоза под нагрузкой

Противоположное колесо не может повернуться, когда ELLIC стоит на полу (под нагрузкой), но
свободно крутится в поднятом состоянии. На лабораторном источнике питания заметных скачков
тока не зафиксировано — это указывает на программное ограничение со стороны ODrive
(лимиты тока/скорости/интегратора), а не на нехватку питания.

- [ ] Прочитать и зафиксировать текущие значения на обоих ODrive:
      `axis0.motor.config.current_lim`
      `axis0.controller.config.vel_gain`
      `axis0.controller.config.vel_integrator_gain`
      `axis0.controller.config.vel_integrator_limit`
      `axis0.encoder.config.enable_phase_interpolation`
      `axis0.encoder.error`
- [ ] Проверить, не упирается ли `TURN_STEP` (0.03 оборота мотора) в статическое трение
      механизма под нагрузкой при текущих `vel_gain`/`current_lim`.
- [ ] По результатам — скорректировать конфигурацию ODrive (раздел 2 этого документа) и
      зафиксировать финальные значения там же.

### 1.3. Дребезг (buzzing) без движения при уменьшении `CONTROL_PERIOD_MS`

Причина понятна: при уменьшении периода цикла управления с 300 мс до 100 мс пропорционально
уменьшается позиционная дельта за цикл; когда дельта падает ниже порога механического
трогания (stiction) механизма, колесо гудит, но не двигается.

- [ ] Решить, нужно ли вообще уменьшать `CONTROL_PERIOD_MS` (300 мс сейчас — нормативное
      значение, раздел 5 спецификации) или проблема снята сама по факту того, что менять его
      не требуется.
- [ ] Если уменьшение периода нужно по другим причинам (отзывчивость управления) — рассмотреть
      альтернативы: увеличение `TURN_STEP`/усиления при том же периоде, либо программную
      компенсацию (накопление под-порогового движения до срабатывания трогания).

### 1.4. [UART, требует проверки] Потеря UART-связи под нагрузкой

Исторический пункт из периода работы по UART: один или оба ODrive переставали отвечать
(`rx` замирал, `rx_fail` рос, `online` падал), оставаясь при этом живыми по USB. Найденные
причины (конфликт GPIO5 как strapping-пина ESP32, `uart0_protocol` 3→1, интервалы
`delay(MOVE_INTER_CMD_DELAY_MS)` в `moveWheel()`) относились к протоколу UART.

- [ ] Подтвердить, что архитектура окончательно перешла на CAN Simple (текущий код уже это
      подтверждает — `ODriveUART.h/.cpp` в переданных файлах отсутствует, есть только
      `ODriveCAN.h/.cpp`).
- [ ] Если UART-путь окончательно не используется — закрыть этот пункт как исторический,
      без переноса в код (GPIO5→GPIO27, три `delay()` в `moveWheel()` относятся к UART API и
      неприменимы к CAN-кадрам напрямую).
- [ ] Если UART всё же используется параллельно (например, для иной цели, не для управления
      ODrive) — уточнить, где именно, и перенести пункт в актуальный раздел.

### 1.5. Аналог "зависания" для CAN-канала

Раздел 13 спецификации описывает `online`/`offline` по факту получения валидных CAN-кадров
(`CAN_NODE_STALE_MS = 300 мс`), но не описывает отдельный механизм ресинхронизации протокола
(аналог прежнего `_moveRecoveryRequired` из UART-эпохи, который пересинхронизировал
запрос/ответ). Для CAN Simple, поскольку сообщения периодические и без запроса/ответа в
привычном смысле, такой механизм, вероятно, не нужен.

- [ ] Подтвердить, что `_moveRecoveryRequired` (или его аналог) не переносится в
      `ODriveCAN` и не требуется — асинхронный приём кадров и `online`/`offline` по
      таймауту это уже покрывают (раздел 13.6 спецификации).

### 1.6. Расхождение текста раздела 11 спецификации с `main.cpp`

Раздел 11 спецификации (схема `loop()`) упоминает шаг `updateConfigure()`, которого нет в
текущем `main.cpp`, и не упоминает `odriveCAN.update()`, который в `main.cpp` есть и
вызывается на каждом проходе `loop()` (приём CAN-кадров, раздел 14.1).

- [ ] Обновить текст раздела 11 спецификации, чтобы отражал фактический код: убрать
      `updateConfigure()`, добавить `odriveCAN.update()`.
- [ ] Это правка спецификации, а не кода — вносить после подтверждения, что `main.cpp`
      является источником истины (изменений в этом цикле разработки не планируется).

### 1.7. Проверка конфигурации ODrive (см. раздел 2 ниже)

Раздел 10.2 спецификации фиксирует: конфигурация ODrive выполняется заранее через
`odrivetool` и не отправляется с ESP32 в runtime. Нужно свести воедино и проверить на
обоих ODrive весь набор параметров, необходимых для корректной работы CAN Simple +
TRAP_TRAJ позиционного управления (см. раздел 2).

- [ ] Прогнать чек-лист раздела 2 по обоим ODrive (LEFT node_id=2, RIGHT node_id=1).
- [ ] Сохранить итоговый конфиг каждого ODrive (`odrivetool backup-config`) в репозиторий
      (например, `firmware/odrive_config/left.json`, `right.json`) для воспроизводимости.

---

## 2. Конфигурация ODrive (v0.5.6, CAN Simple, TRAP_TRAJ позиционное управление)

Ниже — сведённый список параметров, которые должны быть сохранены **в самом ODrive**
(`odrivetool`, через USB, заранее — раздел 10.2 спецификации). ESP32 их не отправляет.
Точные имена атрибутов приведены по документации ODrive v0.5.6; при работе в `odrivetool`
рекомендуется проверять автодополнением (`odrv0.axis0.config.<Tab>` и т.п.), так как часть
имён менялась между минорными версиями 0.5.x/0.6.x.

Выполняется **одинаково на обоих ODrive** (LEFT и RIGHT), если не указано иное.

### 2.1. node_id и CAN-шина — обязательно, разное на каждом ODrive

| Параметр | RIGHT | LEFT |
|---|---|---|
| `odrv0.axis0.config.can.node_id` | `1` | `2` |
| `odrv0.can.config.baud_rate` | `250000` | `250000` |

После смены `node_id` требуется `odrv0.save_configuration()` и `odrv0.reboot()`.

### 2.2. Периодичность CAN-сообщений диагностики (rate_ms)

Спецификация (раздел 12.0, 16) требует, чтобы циклически приходили: Heartbeat (`0x01`,
включён всегда по умолчанию), Motor Error (`0x03`), Encoder Error (`0x04`), Encoder
Estimates (`0x09`), Iq (`0x14`), Bus Voltage/Current (`0x17`), Controller Error (`0x1D`).
Нулевой `rate_ms` отключает сообщение — все нужные должны быть **ненулевыми**.

| Параметр (ориентировочное имя для fw 0.5.6) | Рекомендуемое значение |
|---|---|
| `axis0.config.can.heartbeat_rate_ms` | обычно фиксирован/не требует правки (проверить) |
| `axis0.config.can.encoder_rate_ms` | `100` |
| `axis0.config.can.motor_error_rate_ms` (или аналог для 0x03) | ненулевое, например `100`–`1000` |
| `axis0.config.can.encoder_error_rate_ms` (для 0x04) | ненулевое |
| `axis0.config.can.controller_error_rate_ms` (для 0x1D) | ненулевое |
| `axis0.config.can.iq_rate_ms` | `100` (см. `iq_rate_ms` в спецификации, раздел 12.0) |
| `axis0.config.can.bus_voltage_rate_ms` (для 0x17) | `100` (см. `bus_vi_rate_ms` в спецификации) |

**Важно:** точные имена полей под error-сообщения (0x03/0x04/0x1D) для fw 0.5.6 нужно
подтвердить автодополнением в `odrivetool` — в разных подверсиях 0.5.x они могли называться
иначе, чем в более новой документации 0.6.x (там часть переименована в `..._msg_rate_ms`).

### 2.3. Управление и режим позиционирования (согласуется с разделом 9 спецификации)

| Параметр | Значение | Комментарий |
|---|---|---|
| `axis0.controller.config.control_mode` | `CONTROL_MODE_POSITION_CONTROL` (`3`) | приём `Set Input Pos` |
| `axis0.controller.config.input_mode` | `INPUT_MODE_TRAP_TRAJ` (**числом `5`**, не `InputMode.PASSTHROUGH`) | подтверждено в этом проекте как исправленный баг — ASCII/CAN Simple протокол ODrive принимает только числовые значения |
| `axis0.trap_traj.config.vel_limit` | по механике/безопасности | ограничивает скорость перемещения к цели в TRAP_TRAJ |
| `axis0.trap_traj.config.accel_limit` | по механике | |
| `axis0.trap_traj.config.decel_limit` | по механике | |
| `axis0.controller.config.vel_limit` | должен быть ≥ `trap_traj.config.vel_limit` | общий лимит скорости контроллера |

### 2.4. Токовые/скоростные лимиты и усиления — центральное место для пункта 1.2 (поворот под нагрузкой)

| Параметр | Комментарий |
|---|---|
| `axis0.motor.config.current_lim` | проверить, не занижен ли относительно нужного момента на TURN_STEP под нагрузкой |
| `axis0.controller.config.vel_gain` | слишком малое значение → вялая/неспособная преодолеть трение реакция |
| `axis0.controller.config.vel_integrator_gain` | накопление ошибки скорости; влияет на способность "дожать" короткое приращение TURN_STEP |
| `axis0.controller.config.vel_integrator_limit` | ограничение интегратора — если занижено, тоже может не дать "дожать" под нагрузкой |
| `axis0.controller.config.pos_gain` | позиционное усиление (TRAP_TRAJ всё равно идёт через позиционный контур) |

Эти пять параметров — прямые кандидаты на объяснение проблемы 1.2 и должны быть сняты и
записаны с реального железа перед изменением.

### 2.5. Энкодер мотора ODrive (Hall, встроенный в мотор-колесо)

Раздел 1 спецификации явно упоминает Hall-датчик мотора (42 такта/оборот), хотя и не
используется для расчётов в ESP32 — но ODrive использует его для коммутации/оценки
скорости своей оси.

| Параметр | Значение | Комментарий |
|---|---|---|
| `axis0.encoder.config.mode` | `ENCODER_MODE_HALL` | если используется штатный Hall-датчик мотора |
| `axis0.encoder.config.cpr` | `42` | 7 пар полюсов × 6 состояний Hall |
| `axis0.encoder.config.enable_phase_interpolation` | проверить текущее значение (пункт 1.2) | влияет на сглаживание при низком разрешении Hall |
| `axis0.encoder.error` | только диагностика | зафиксировать текущее значение, не параметр конфигурации |

### 2.6. Автономный старт без ESP32-конфигурации (критично для раздела 10.2 спецификации)

Поскольку по разделу 10.2 спецификации ESP32 **не отправляет** команды перехода в закрытый
цикл (`AxisState.CLOSED_LOOP_CONTROL`) в runtime, ODrive должен делать это самостоятельно
при подаче питания:

| Параметр | Значение | Комментарий |
|---|---|---|
| `axis0.config.startup_closed_loop_control` | `True` | иначе после включения ODrive останется в IDLE и не будет реагировать на Set Input Pos |

**[Открыто]** Этот параметр не упомянут явно в тексте спецификации — нужно подтвердить, что
он действительно выставлен на обоих ODrive, и при подтверждении добавить явным пунктом в
`ELLIC_spec.md` (раздел 10), так как это критично для работы всей системы по CAN-only схеме.

### 2.7. Watchdog — явно выключен (раздел 13.2 спецификации, уже решено)

| Параметр | Значение |
|---|---|
| `axis0.config.enable_watchdog` | `False` |

Решение уже зафиксировано в спецификации (раздел 13.2) — включён здесь для полноты чек-листа
конфигурации, действий не требует.

### 2.8. Общие ограничения платы (проверить, не входят в предмет данной спецификации, но нужны для безопасной работы)

| Параметр | Комментарий |
|---|---|
| `odrv0.config.dc_bus_undervoltage_trip_level` | под используемую батарею/БП |
| `odrv0.config.dc_bus_overvoltage_trip_level` | под используемую батарею/БП |
| `odrv0.config.dc_max_positive_current` | суммарный лимит потребления |
| `odrv0.config.dc_max_negative_current` | лимит рекуперации (может быть `0`, если рекуперация не нужна/не поддерживается питанием) |
| `odrv0.axis0.motor.config.motor_type` | обычно `MOTOR_TYPE_HIGH_CURRENT` для мотор-колёс |
| `odrv0.axis0.motor.config.pole_pairs` | по паспорту мотора |

---

## 3. Диаграмма состояния задач

```mermaid
flowchart TB
    subgraph OPEN["Открыто"]
        A["1.1 Калибровка TURN_ZONE"]
        B["1.2 Поворот под нагрузкой не работает"]
        C["1.3 Дребезг при CONTROL_PERIOD_MS=100"]
        F["1.7 Свод и бэкап конфигурации ODrive"]
    end

    subgraph REVIEW["Требует подтверждения / исторические (UART)"]
        D["1.4 UART под нагрузкой — вероятно снято переходом на CAN"]
        E["1.5 Аналог _moveRecoveryRequired для CAN — вероятно не нужен"]
        G["1.6 Текст раздела 11 спецификации разошёлся с main.cpp"]
        H["2.6 startup_closed_loop_control — критично, не задокументировано явно"]
    end

    B --> B1["Снять axis0.motor/controller.config.*<br/>(раздел 2.4)"]
    B1 --> B2["Сравнить с реальным поведением под нагрузкой"]
    B2 --> B3["Скорректировать конфиг ODrive"]

    A --> A1["Найти физическое 0°/180°"]
    A1 --> A2["Ввести смещение или переустановить датчик"]

    C --> C1{"Действительно нужно уменьшать период?"}
    C1 -->|Да| C2["Компенсировать TURN_STEP/усилениями"]
    C1 -->|Нет| C3["Оставить CONTROL_PERIOD_MS = 300 мс"]

    F --> F1["odrivetool backup-config LEFT/RIGHT"]
    F1 --> F2["Сохранить json в репозиторий"]
```

---

## 4. История решённых вопросов (перенесено из примечаний спецификации)

Ниже — обсуждение, которое привело к текущим нормативным решениям в `ELLIC_spec.md`
(разделы 4, 10.4, 12.0, 16). Сохранено как история, самих решений это не меняет.

### Вопрос 1 — диагностика (решено)

Для ODrive v0.5.6:

| Параметр CAN Simple | Payload |
|---|---|
| `axis0.error` — `0x01` Heartbeat | Axis_Error = uint32 |
| `axis0.motor.error` — `0x03` Get Motor Error | uint32 |
| `axis0.controller.error` — `0x1D` Get Controller Error | uint32 |
| `Iq` — `0x14` Get Iq | Iq_Setpoint + Iq_Measured, два float |
| `Vel_Estimate` — `0x09` | второй float (вместе с Pos_Estimate) |
| Bus Voltage/Current — `0x17` | два float |

CAN Simple ODrive v0.5.6 добавил циклические сообщения для motor error, controller error,
Iq и Bus Voltage/Current. **Vq отдельного CAN Simple сообщения в v0.5.6 нет** — его не нужно
придумывать.

Итоговое решение для `TelemetrySample`: `axisError`, `motorError`, `controllerError`, `Iq`,
`Vel_Estimate`, `BusVoltage`, `BusCurrent`. `Vq` **удалён** из спецификации. Для `Iq`
используется `Iq_Measured` как фактический ток мотора; `BusCurrent` — отдельно, это ток
потребления от DC-шины. `0x14` передаёт Setpoint и Measured Iq, `0x17` — Bus Voltage и Bus
Current. Для циклической передачи достаточно задать ненулевые `rate_ms` для `0x03`, `0x1D`,
`0x14` и `0x17`; нулевой `rate_ms` отключает сообщение.

### Вопрос 2 — Procedure_Result (решено)

Для ODrive firmware v0.5.6 `Procedure_Result` в Heartbeat нет. Heartbeat v0.5.6 содержит:
`Axis_Error`, `Axis_State`, `Motor_Error_Flag`, `Encoder_Error_Flag`,
`Controller_Error_Flag`, `Trajectory_Done_Flag`. Отдельный CAN ID для `Procedure_Result`
искать не нужно — он и не требуется для задачи.

Решение: `Procedure_Result` **удалён** из спецификации и из `OdriveSnapshot`. Оставлены:
`axisState`, `axisError`, `motorError`, `encoderError`, `controllerError`, `trajectoryDone`.
При этом `motorError`, `encoderError`, `controllerError` получаются отдельными сообщениями
`0x03`, `0x04`, `0x1D`. Это соответствует именно v0.5.6, а не более новым описаниям CAN — в
changelog v0.5.6 отдельно указано, что Heartbeat получил флаги ошибок, а сами ошибки нужно
получать соответствующими сообщениями.

### Вопрос 3 — ESP32 CAN (решено)

Решено освободить старые UART-пины и использовать их под CAN:

- ESP32 GPIO16 → SN65HVD230 TX
- ESP32 GPIO17 ← SN65HVD230 RX

Это нормальная разводка для ESP32 TWAI и не затрагивает: AS5600 (GPIO21/22), тормоза
(GPIO32/33), джойстик GPIO27, старые UART-пины (больше не нужны).

**CAN bitrate: 250 kbit/s** — выбран сознательно вместо 500 kbit/s: для двух ODrive и
небольшого объёма телеметрии этого достаточно, вариант консервативнее.

CAN ID формируется стандартно: `CAN_ID = (node_id << 5) | command_id`. Для RIGHT (node_id=1)
физические ID: Heartbeat = `0x21`, Encoder = `0x29`, Input Position = `0x2C`, Iq = `0x34`,
Bus V/I = `0x37`, Motor Error = `0x23`, Controller Err = `0x3D`. Для LEFT (node_id=2) —
соответственно `0x40 + command_id`.

**Итого зафиксировано в спецификации** (перенесено в `ELLIC_spec.md`, разделы 4 и 16):
CAN — ESP32 TWAI, TX=GPIO16, RX=GPIO17, bitrate=250000 бит/с, transceiver=SN65HVD230.
ODrive diagnostics: `0x01` Heartbeat, `0x03` Motor Error, `0x04` Encoder Error, `0x09`
Encoder Estimates, `0x14` Iq, `0x17` Bus Voltage/Current, `0x1D` Controller Error. Удалено:
Vq, Procedure_Result.

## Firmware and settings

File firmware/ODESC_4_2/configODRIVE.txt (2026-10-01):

{"axis0": {"acim_estimator": {"config": {"slip_velocity": 14.706000328063965}}, "config": {"dir_gpio_pin": 2, "enable_sensorless_mode": false, "enable_step_dir": false, "enable_watchdog": false, "startup_closed_loop_control": true, "startup_encoder_index_search": false, "startup_encoder_offset_calibration": false, "startup_homing": false, "startup_motor_calibration": false, "step_dir_always_on": false, "step_gpio_pin": 1, "watchdog_timeout": 0.0, "calibration_lockin": {"accel": 20.0, "current": 10.0, "ramp_distance": 3.1415927410125732, "ramp_time": 0.4000000059604645, "vel": 40.0}, "can": {"bus_vi_rate_ms": 100, "controller_error_rate_ms": 100, "encoder_count_rate_ms": 0, "encoder_error_rate_ms": 100, "encoder_rate_ms": 100, "heartbeat_rate_ms": 100, "iq_rate_ms": 100, "is_extended": false, "motor_error_rate_ms": 100, "node_id": 1, "sensorless_error_rate_ms": 0, "sensorless_rate_ms": 0}, "general_lockin": {"accel": 20.0, "current": 10.0, "finish_distance": 100.0, "finish_on_distance": false, "finish_on_enc_idx": false, "finish_on_vel": false, "ramp_distance": 3.1415927410125732, "ramp_time": 0.4000000059604645, "vel": 40.0}, "sensorless_ramp": {"accel": 200.0, "current": 10.0, "finish_distance": 100.0, "finish_on_distance": false, "finish_on_enc_idx": false, "finish_on_vel": true, "ramp_distance": 3.1415927410125732, "ramp_time": 0.4000000059604645, "vel": 400.0}}, "controller": {"config": {"axis_to_mirror": 255, "circular_setpoint_range": 1.0, "circular_setpoints": false, "control_mode": 3, "electrical_power_bandwidth": 20.0, "enable_gain_scheduling": true, "enable_overspeed_error": false, "enable_torque_mode_vel_limit": true, "enable_vel_limit": true, "gain_scheduling_width": 5.0, "homing_speed": 0.25, "inertia": 0.0, "input_filter_bandwidth": 8.0, "input_mode": 5, "load_encoder_axis": 0, "mechanical_power_bandwidth": 20.0, "mirror_ratio": 1.0, "pos_gain": 3.0, "spinout_electrical_power_threshold": 10.0, "spinout_mechanical_power_threshold": -10.0, "steps_per_circular_range": 1024, "torque_mirror_ratio": 0.0, "torque_ramp_rate": 0.009999999776482582, "vel_gain": 0.5, "vel_integrator_gain": 0.1599999964237213, "vel_integrator_limit": Infinity, "vel_limit": 2.0, "vel_limit_tolerance": 1.2000000476837158, "vel_ramp_rate": 1.0, "anticogging": {"anticogging_enabled": true, "calib_anticogging": false, "calib_pos_threshold": 1.0, "calib_vel_threshold": 1.0, "cogging_ratio": 1.0, "index": 0, "pre_calibrated": false}}}, "encoder": {"config": {"abs_spi_cs_gpio_pin": 1, "bandwidth": 1000.0, "calib_range": 0.019999999552965164, "calib_scan_distance": 50.26548385620117, "calib_scan_omega": 12.566370964050293, "cpr": 42, "direction": 1, "enable_phase_interpolation": false, "find_idx_on_lockin_only": false, "hall_polarity_calibrated": true, "hall_polarity": 0, "ignore_illegal_hall_state": false, "index_offset": 0.0, "mode": 1, "phase_offset_float": 0.5013751983642578, "phase_offset": 25, "pre_calibrated": true, "sincos_gpio_pin_cos": 4, "sincos_gpio_pin_sin": 3, "use_index_offset": true, "use_index": false}}, "max_endstop": {"config": {"debounce_ms": 50, "enabled": false, "gpio_num": 0, "is_active_high": false, "offset": 0.0}}, "mechanical_brake": {"config": {"gpio_num": 0, "is_active_low": true}}, "min_endstop": {"config": {"debounce_ms": 50, "enabled": false, "gpio_num": 0, "is_active_high": false, "offset": 0.0}}, "motor": {"config": {"I_bus_hard_max": Infinity, "I_bus_hard_min": -Infinity, "I_leak_max": 0.10000000149011612, "R_wL_FF_enable": false, "acim_autoflux_attack_gain": 10.0, "acim_autoflux_decay_gain": 1.0, "acim_autoflux_enable": false, "acim_autoflux_min_Id": 10.0, "acim_gain_min_flux": 10.0, "bEMF_FF_enable": false, "calibration_current": 5.0, "current_control_bandwidth": 1000.0, "current_lim_margin": 8.0, "current_lim": 10.0, "dc_calib_tau": 0.20000000298023224, "inverter_temp_limit_lower": 100.0, "inverter_temp_limit_upper": 120.0, "motor_type": 0, "phase_inductance": 0.00020352363935671747, "phase_resistance": 0.17645108699798584, "pole_pairs": 7, "pre_calibrated": true, "requested_current_range": 60.0, "resistance_calib_max_voltage": 2.0, "torque_constant": 0.03999999910593033, "torque_lim": Infinity}, "fet_thermistor": {"config": {"enabled": true, "temp_limit_lower": 100.0, "temp_limit_upper": 120.0}}, "motor_thermistor": {"config": {"enabled": false, "gpio_pin": 4, "poly_coefficient_0": 0.0, "poly_coefficient_1": 0.0, "poly_coefficient_2": 0.0, "poly_coefficient_3": 0.0, "temp_limit_lower": 100.0, "temp_limit_upper": 120.0}}}, "sensorless_estimator": {"config": {"observer_gain": 1000.0, "pll_bandwidth": 1000.0, "pm_flux_linkage": 0.0015800000401213765}}, "trap_traj": {"config": {"accel_limit": 10.0, "decel_limit": 10.0, "vel_limit": 2.0}}}, "axis1": {"acim_estimator": {"config": {"slip_velocity": 14.706000328063965}}, "config": {"dir_gpio_pin": 8, "enable_sensorless_mode": false, "enable_step_dir": false, "enable_watchdog": false, "startup_closed_loop_control": false, "startup_encoder_index_search": false, "startup_encoder_offset_calibration": false, "startup_homing": false, "startup_motor_calibration": false, "step_dir_always_on": false, "step_gpio_pin": 7, "watchdog_timeout": 0.0, "calibration_lockin": {"accel": 20.0, "current": 10.0, "ramp_distance": 3.1415927410125732, "ramp_time": 0.4000000059604645, "vel": 40.0}, "can": {"bus_vi_rate_ms": 0, "controller_error_rate_ms": 0, "encoder_count_rate_ms": 0, "encoder_error_rate_ms": 0, "encoder_rate_ms": 0, "heartbeat_rate_ms": 0, "iq_rate_ms": 0, "is_extended": false, "motor_error_rate_ms": 0, "node_id": 7, "sensorless_error_rate_ms": 0, "sensorless_rate_ms": 0}, "general_lockin": {"accel": 20.0, "current": 10.0, "finish_distance": 100.0, "finish_on_distance": false, "finish_on_enc_idx": false, "finish_on_vel": false, "ramp_distance": 3.1415927410125732, "ramp_time": 0.4000000059604645, "vel": 40.0}, "sensorless_ramp": {"accel": 200.0, "current": 10.0, "finish_distance": 100.0, "finish_on_distance": false, "finish_on_enc_idx": false, "finish_on_vel": true, "ramp_distance": 3.1415927410125732, "ramp_time": 0.4000000059604645, "vel": 400.0}}, "controller": {"config": {"axis_to_mirror": 255, "circular_setpoint_range": 1.0, "circular_setpoints": false, "control_mode": 3, "electrical_power_bandwidth": 20.0, "enable_gain_scheduling": false, "enable_overspeed_error": true, "enable_torque_mode_vel_limit": true, "enable_vel_limit": true, "gain_scheduling_width": 10.0, "homing_speed": 0.25, "inertia": 0.0, "input_filter_bandwidth": 2.0, "input_mode": 1, "load_encoder_axis": 1, "mechanical_power_bandwidth": 20.0, "mirror_ratio": 1.0, "pos_gain": 20.0, "spinout_electrical_power_threshold": 10.0, "spinout_mechanical_power_threshold": -10.0, "steps_per_circular_range": 1024, "torque_mirror_ratio": 0.0, "torque_ramp_rate": 0.009999999776482582, "vel_gain": 0.1666666716337204, "vel_integrator_gain": 0.3333333432674408, "vel_integrator_limit": Infinity, "vel_limit": 2.0, "vel_limit_tolerance": 1.2000000476837158, "vel_ramp_rate": 1.0, "anticogging": {"anticogging_enabled": true, "calib_anticogging": false, "calib_pos_threshold": 1.0, "calib_vel_threshold": 1.0, "cogging_ratio": 1.0, "index": 0, "pre_calibrated": false}}}, "encoder": {"config": {"abs_spi_cs_gpio_pin": 1, "bandwidth": 1000.0, "calib_range": 0.019999999552965164, "calib_scan_distance": 50.26548385620117, "calib_scan_omega": 12.566370964050293, "cpr": 8192, "direction": 0, "enable_phase_interpolation": true, "find_idx_on_lockin_only": false, "hall_polarity_calibrated": false, "hall_polarity": 0, "ignore_illegal_hall_state": false, "index_offset": 0.0, "mode": 0, "phase_offset_float": 0.0, "phase_offset": 0, "pre_calibrated": false, "sincos_gpio_pin_cos": 4, "sincos_gpio_pin_sin": 3, "use_index_offset": true, "use_index": false}}, "max_endstop": {"config": {"debounce_ms": 50, "enabled": false, "gpio_num": 0, "is_active_high": false, "offset": 0.0}}, "mechanical_brake": {"config": {"gpio_num": 0, "is_active_low": true}}, "min_endstop": {"config": {"debounce_ms": 50, "enabled": false, "gpio_num": 0, "is_active_high": false, "offset": 0.0}}, "motor": {"config": {"I_bus_hard_max": Infinity, "I_bus_hard_min": -Infinity, "I_leak_max": 0.10000000149011612, "R_wL_FF_enable": false, "acim_autoflux_attack_gain": 10.0, "acim_autoflux_decay_gain": 1.0, "acim_autoflux_enable": false, "acim_autoflux_min_Id": 10.0, "acim_gain_min_flux": 10.0, "bEMF_FF_enable": false, "calibration_current": 10.0, "current_control_bandwidth": 1000.0, "current_lim_margin": 8.0, "current_lim": 10.0, "dc_calib_tau": 0.20000000298023224, "inverter_temp_limit_lower": 100.0, "inverter_temp_limit_upper": 120.0, "motor_type": 0, "phase_inductance": 0.0, "phase_resistance": 0.0, "pole_pairs": 7, "pre_calibrated": false, "requested_current_range": 60.0, "resistance_calib_max_voltage": 2.0, "torque_constant": 0.03999999910593033, "torque_lim": Infinity}, "fet_thermistor": {"config": {"enabled": true, "temp_limit_lower": 100.0, "temp_limit_upper": 120.0}},
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

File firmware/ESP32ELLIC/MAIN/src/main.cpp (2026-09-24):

#include <Arduino.h>
#include <Wire.h>
#include "Config.h"
#include "Encoder.h"
#include "MotionController.h"
#include "ODriveCAN.h"
#include "Telemetry.h"
#include "BleTelemetry.h"
// #include "EllicVRButton.h"
// ВАЖНО: EllicVRButton (BleGamepad) и BleTelemetry - оба поднимают BLE-стек
// на ESP32. Пока EllicVRButton закомментирован, конфликта нет. Если его
// снова включат, нельзя просто раскомментировать: два независимых вызова
// инициализации BLE с высокой вероятностью конфликтуют (один BLE-радио на
// устройство) - оба модуля тогда нужно свести на один и тот же стек.

// Раздел 0: main.cpp содержит один экземпляр ODriveCAN, обслуживающий оба
// логических канала (RIGHT node_id=1, LEFT node_id=2).
Encoder encoder;
MotionController motionController;
ODriveCAN odriveCAN;

Telemetry telemetry(&encoder, &motionController, &odriveCAN);
BleTelemetry bleTelemetry;

// EllicVRButton vrButton("ELLIC VR Gamepad", 18);

uint32_t lastControlMs = 0;

void setup() {
    
    /// WRITE_PERI_REG(RTC_CNTL_BROWN_OUT_REG, 0); // ВРЕМЕННО: отключает brownout-детектор

    Serial.begin(115200);

    Wire.begin(AS5600_SDA_PIN, AS5600_SCL_PIN);
    Wire.setClock(AS5600_I2C_CLOCK_HZ);

    pinMode(LEFT_BRAKE_PIN, INPUT_PULLUP);
    pinMode(RIGHT_BRAKE_PIN, INPUT_PULLUP);

    telemetry.begin(LogLevel::INFO);

    encoder.begin(&telemetry);
    motionController.begin();

    odriveCAN.setTelemetry(&telemetry);
    odriveCAN.begin();

    /// delay(5000); // диагностическая пауза перед стартом BLE    
    
    bleTelemetry.begin("ELLIC Telemetry");
    telemetry.setBleTelemetry(&bleTelemetry);

    // vrButton.begin();

    // Раздел 10.1/10.2: явная ASCII-конфигурация ODrive из ESP32 не
    // выполняется. При работе по CAN она не предусмотрена в принципе -
    // соответствующего метода в ODriveCAN намеренно нет.

    telemetry.log(LogLevel::INFO, "main", "ELLIC system initialized (CAN)");

    lastControlMs = millis();
}

void loop() {
    // Раздел 11: encoder.update() - на каждом проходе, без периода.
    encoder.update();

    // Раздел 14.1: приём CAN-кадров и обновление кэша/online-статуса
    // выполняется на каждом проходе loop(), не блокируясь телеметрией.
    odriveCAN.update();

    // Обслуживает переподключения BLE-клиента телеметрии.
    bleTelemetry.update();

    uint32_t now = millis();
    if (now - lastControlMs >= CONTROL_PERIOD_MS) {
        lastControlMs = now;

        bool leftBrake  = (digitalRead(LEFT_BRAKE_PIN) == LOW);
        bool rightBrake = (digitalRead(RIGHT_BRAKE_PIN) == LOW);

        EncoderSnapshot encSnap = encoder.getSnapshot();

        // Разделы 6.2-8: общее решение по ОБОИМ тормозам + Val сразу
        // даёт оба приращения - leftWheelDelta и rightWheelDelta.
        motionController.update(encSnap.rawAngle, encSnap.continuousAngle,
                                 leftBrake, rightBrake);

        // Раздел 9/14.2: дальше каналы независимы - недоступная/устаревшая
        // позиция одного колеса не блокирует отправку команды другому.
        odriveCAN.moveLeftWheel(motionController.getLeftWheelDelta());
        odriveCAN.moveRightWheel(motionController.getRightWheelDelta());
    }

    // Раздел 12: телеметрия - собственные периоды collect()/printScheduled().
    telemetry.update();

    // vrButton.update();
}

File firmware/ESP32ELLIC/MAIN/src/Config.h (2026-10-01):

#pragma once
#include <Arduino.h>

// =======================================================================
// Аппаратные подключения (раздел 4 спецификации)
// =======================================================================

// AS5600 (I2C)
#define AS5600_SDA_PIN 21
#define AS5600_SCL_PIN 22
#define AS5600_I2C_CLOCK_HZ 50000

// AS5600 регистр RAW ANGLE (12 бит, 0x0C/0x0D)
#define AS5600_I2C_ADDR 0x36
#define AS5600_RAW_ANGLE_REG 0x0C

// Тормоза
#define LEFT_BRAKE_PIN 32 // второй провод на землю
#define RIGHT_BRAKE_PIN 33 // второй провод на землю
// Тормоз нажат при digitalRead(pin) == LOW (см. раздел 4)

// CAN (ESP32 TWAI, транссивер SN65HVD230, раздел 4 / "Вопрос 3")
#define CAN_TX_PIN 16
#define CAN_RX_PIN 17
static const uint32_t CAN_BITRATE = 250000; // бит/с

// =======================================================================
// Константы (раздел 5 спецификации)
// =======================================================================

static const uint32_t CONTROL_PERIOD_MS      = 300;   // период MotionController.update()
static const float    MOTOR_GEAR_RATIO       = 6.4f;  // передаточное число редуктора
static const float    TURN_ZONE_DEG          = 10.0f; // ширина зоны поворота
static const float    TURN_STEP              = 1.0f; // шаг противоположного колеса при повороте (оборотов)

static const float    ENCODER_SIGN           = -1.0f; // инверсия направления энкодера (только для NORMAL)

static const float    LEFT_WHEEL_SIGN        = 1.0f;
static const float    RIGHT_WHEEL_SIGN       = -1.0f;

static const uint32_t TELEMETRY_PERIOD_MS       = 150; // период collect()
static const uint32_t TELEMETRY_PRINT_PERIOD_MS = 1000; // период printScheduled() (~10 Гц)

static const uint32_t CAN_NODE_STALE_MS = 300; // раздел 5/13: порог offline

// CAN node_id (раздел 4.3, 10.3)
static const uint8_t RIGHT_ODRIVE_NODE_ID = 1;
static const uint8_t LEFT_ODRIVE_NODE_ID  = 2;

// =======================================================================
// Общие перечисления и структуры-снапшоты (раздел 12.3)
// =======================================================================

enum class LogLevel { INFO, WARNING, ERROR, CRITICAL };

enum class MotionMode { NORMAL, CALM, TURN };

struct EncoderSnapshot {
    float rawAngle;        // последнее валидное значение AS5600, 0..360
    float continuousAngle; // накопленный (безразрывный) угол
    float lastDelta;       // последняя дельта, посчитанная в Encoder::update()
};

struct MotionSnapshot {
    float valDelta;
    float leftWheelDelta;
    float rightWheelDelta;
    MotionMode mode;
    bool leftBrake;
    bool rightBrake;
    bool inTurnZone;
};

// Раздел 12.3 + финальные решения "Вопрос 1/2" из спецификации:
// Vq и Procedure_Result исключены; добавлены encoderError, trajectoryDone,
// busVoltage/busCurrent (см. ODriveCAN.cpp).
struct OdriveSnapshot {
    bool online;

    int      axisState;
    uint32_t axisError;
    uint64_t motorError;       // Get Motor Error (0x03) - 64 бита у fw 0.5.6!
    uint32_t encoderError;     // Get Encoder Error (0x04)
    uint32_t controllerError;  // Get Controller Error (0x1D)
    bool     trajectoryDone;   // Heartbeat.Trajectory_Done_Flag

    float Iq;           // Get Iq (0x14), Iq_Measured
    float velEstimate;  // Get Encoder Estimates (0x09), Vel_Estimate
    float busVoltage;   // Get Bus Voltage Current (0x17)
    float busCurrent;   // Get Bus Voltage Current (0x17)

    uint32_t txCount;
    uint32_t rxCount;
    uint32_t rxFailCount;
    uint32_t diagnosticsTimestampMs;
};

struct TelemetrySample {
    EncoderSnapshot encoder;
    MotionSnapshot  motion;
    OdriveSnapshot  left;
    OdriveSnapshot  right;
};

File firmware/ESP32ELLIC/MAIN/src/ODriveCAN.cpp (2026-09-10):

#include "ODriveCAN.h"
#include "Telemetry.h"
#include "driver/twai.h"
#include <string.h>

namespace {
// CAN Simple command ID для fw 0.5.6 (раздел 9, 10.4, 12.0,
// "Итого зафиксировал в спецификации")
constexpr uint8_t CMD_HEARTBEAT             = 0x01;
constexpr uint8_t CMD_GET_MOTOR_ERROR       = 0x03;
constexpr uint8_t CMD_GET_ENCODER_ERROR     = 0x04;
constexpr uint8_t CMD_GET_ENCODER_ESTIMATES = 0x09;
constexpr uint8_t CMD_SET_INPUT_POS         = 0x0C;
constexpr uint8_t CMD_GET_IQ                = 0x14;
constexpr uint8_t CMD_GET_BUS_VI            = 0x17;
constexpr uint8_t CMD_GET_CONTROLLER_ERROR  = 0x1D;

uint32_t readU32(const uint8_t* p) {
    uint32_t v;
    memcpy(&v, p, sizeof(v));
    return v;
}

uint64_t readU64(const uint8_t* p) {
    uint64_t v;
    memcpy(&v, p, sizeof(v));
    return v;
}

float readF32(const uint8_t* p) {
    float v;
    memcpy(&v, p, sizeof(v));
    return v;
}
} // namespace

ODriveCAN::ODriveCAN() : _telemetry(nullptr) {
    initChannel(_right, RIGHT_ODRIVE_NODE_ID, "RIGHT");
    initChannel(_left, LEFT_ODRIVE_NODE_ID, "LEFT");
}

void ODriveCAN::initChannel(WheelChannel &ch, uint8_t nodeId, const char* label) {
    ch.nodeId = nodeId;
    ch.label = label;
    ch.online = false;
    ch.everReceivedFrame = false;
    ch.lastFrameMs = 0;
    ch.hasValidPosition = false;
    ch.lastPosEstimateMs = 0;
    ch.posEstimate = 0.0f;
    ch.velEstimate = 0.0f;
    ch.axisState = 0;
    ch.axisError = 0;
    ch.motorError = 0;
    ch.encoderError = 0;
    ch.controllerError = 0;
    ch.trajectoryDone = false;
    ch.Iq = 0.0f;
    ch.busVoltage = 0.0f;
    ch.busCurrent = 0.0f;
    ch.txCount = 0;
    ch.rxCount = 0;
    ch.rxFailCount = 0;
    ch.diagnosticsTimestampMs = 0;
}

void ODriveCAN::setTelemetry(Telemetry* telemetry) {
    _telemetry = telemetry;
}

void ODriveCAN::begin() {
    twai_general_config_t g_config = TWAI_GENERAL_CONFIG_DEFAULT(
        (gpio_num_t)CAN_TX_PIN, (gpio_num_t)CAN_RX_PIN, TWAI_MODE_NORMAL);
    twai_timing_config_t t_config = TWAI_TIMING_CONFIG_250KBITS();
    twai_filter_config_t f_config = TWAI_FILTER_CONFIG_ACCEPT_ALL();

    twai_driver_install(&g_config, &t_config, &f_config);
    twai_start();
}

ODriveCAN::WheelChannel* ODriveCAN::channelForNode(uint8_t nodeId) {
    if (nodeId == _right.nodeId) return &_right;
    if (nodeId == _left.nodeId) return &_left;
    return nullptr;
}

void ODriveCAN::processFrame(uint32_t canId, const uint8_t* data, uint8_t dlc, uint32_t nowMs) {
    uint8_t nodeId = (uint8_t)((canId >> 5) & 0x3F);
    uint8_t cmdId  = (uint8_t)(canId & 0x1F);

    WheelChannel* chPtr = channelForNode(nodeId);
    if (chPtr == nullptr) {
        return; // кадр от неизвестного node_id - игнорируется
    }
    WheelChannel &ch = *chPtr;

    bool wasOffline = !ch.online;
    ch.everReceivedFrame = true;
    ch.lastFrameMs = nowMs;
    ch.online = true;
    ch.rxCount++;

    if (wasOffline && _telemetry != nullptr) {
        _telemetry->log(LogLevel::INFO, ch.label, "ODrive CAN: online");
    }

    switch (cmdId) {
        case CMD_HEARTBEAT:
            // Раздел 10.4: Axis_Error(u32 @0) Axis_State(u8 @4)
            // Motor/Encoder/Controller_Error_Flag(бит @5.0/6.0/7.0) Trajectory_Done_Flag(бит @7.7)
            if (dlc >= 8) {
                ch.axisError = readU32(&data[0]);
                ch.axisState = data[4];
                ch.trajectoryDone = (data[7] & 0x80) != 0;
                ch.diagnosticsTimestampMs = nowMs;
            }
            break;

        case CMD_GET_MOTOR_ERROR:
            // Внимание: у fw 0.5.6 это поле 64-битное (см. отчёт после кода).
            if (dlc >= 8) {
                ch.motorError = readU64(&data[0]);
                ch.diagnosticsTimestampMs = nowMs;
            }
            break;

        case CMD_GET_ENCODER_ERROR:
            if (dlc >= 4) {
                ch.encoderError = readU32(&data[0]);
                ch.diagnosticsTimestampMs = nowMs;
            }
            break;

        case CMD_GET_ENCODER_ESTIMATES:
            if (dlc >= 8) {
                ch.posEstimate = readF32(&data[0]);
                ch.velEstimate = readF32(&data[4]);
                ch.hasValidPosition = true;
                ch.lastPosEstimateMs = nowMs;
                ch.diagnosticsTimestampMs = nowMs;
            }
            break;

        case CMD_GET_IQ:
            // байты 0..3 - Iq_Setpoint (не используется, "Вопрос 1" спецификации),
            // байты 4..7 - Iq_Measured (используется как фактический ток мотора).
            if (dlc >= 8) {
                ch.Iq = readF32(&data[4]);
                ch.diagnosticsTimestampMs = nowMs;
            }
            break;

        case CMD_GET_BUS_VI:
            if (dlc >= 8) {
                ch.busVoltage = readF32(&data[0]);
                ch.busCurrent = readF32(&data[4]);
                ch.diagnosticsTimestampMs = nowMs;
            }
            break;

        case CMD_GET_CONTROLLER_ERROR:
            if (dlc >= 4) {
                ch.controllerError = readU32(&data[0]);
                ch.diagnosticsTimestampMs = nowMs;
            }
            break;

        default:
            // Прочие CAN Simple сообщения (Get_Version, Encoder Count и т.п.)
            // системой не используются и игнорируются.
            break;
    }
}

void ODriveCAN::refreshOnlineState(uint32_t nowMs) {
    WheelChannel* channels[2] = { &_right, &_left };
    for (WheelChannel* chPtr : channels) {
        WheelChannel &ch = *chPtr;
        if (ch.online && ch.everReceivedFrame &&
            (nowMs - ch.lastFrameMs) > CAN_NODE_STALE_MS) {
            ch.online = false;
            if (_telemetry != nullptr) {
                _telemetry->log(LogLevel::WARNING, ch.label, "ODrive CAN: offline (stale)");
            }
        }
    }
}

void ODriveCAN::update() {
    twai_message_t msg;
    // Раздел 14.1/14.3: приём всех доступных кадров без блокировки.
    while (twai_receive(&msg, 0) == ESP_OK) {
        if (!msg.rtr) {
            processFrame(msg.identifier, msg.data, msg.data_length_code, millis());
        }
    }
    refreshOnlineState(millis());
}
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

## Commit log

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2026-03-13 Сдел файловую структуру но не пойму она отражается или нет в файлах
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2026-03-13 Описание ваших изменений, например: Исправил структуру папок, добавил гифки
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2026-03-15 add версии и расходы2
    [Затраты на Эллик.xlsx]
2026-03-16 Вставил кады и сделал к ним описание мехнизма
    [EllicV14FUSION.f3d, EllicV14PROTOROS.step]
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2026-03-18 start to razbirat components of model fusion
    [Motor.f3d, SBR_Koleso_Stupitca.f3d, Wheel_d24_nonMotored.f3d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]
2026-03-18 Change name wheels compons
    [Wheel_d24_nonMotored.f3d, Wheel_d24_nonMotored_1.f3d]
2026-03-18 sdelal sborku kolesa
    [SBR_Koleso_Stupitca.f3d]
2026-03-19 создал cronshobot
    [CronsHobot.f3d, Motor.f3d, SBR_Koleso_Stupitca.f3d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]
2026-03-20 add manufacturing
    [MountPlate.f3d]
2026-03-20 first dxf
    [MountPlate.f3d, laser_mountplate_10mm_EllicV15.dxf]
2026-03-20 dal dxf
    [CronsHobot.f3d, SBR_Koleso_Stupitca.f3d, laser_frontplate_10mm_ellicV15.dxf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]
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2026-04-06 сделал стл держателя оптческого энкодера. добавил род а в веботс
    [derjOptEnc.f3d, derjOptEnc.stl]
2026-04-06 Скругленные грани держателя оптического энкодера
    [derjOptEnc.f3d, derjOptEnc.stl]
2026-04-09 Obves v1
    [ChelSTL.stl, Ellic_Obves.f3d]
2026-04-09 передний шилд 2
    [Ellic_Obves.f3d]
2026-04-09 отверстия 1\2
    [Ellic_Obves.f3d]
2026-04-09 отерстия почти все
    [Ellic_Obves.f3d]
2026-04-09 обвес с вырезами под раму
    [Ellic_Obves.f3d]
2026-04-09 footPn сделан правильно
    [Ellic_Obves.f3d]
2026-04-09 сделан правый бок
    [Ellic_Obves.f3d]
2026-04-10 готовые панели левая и правая сторона
    [Ellic_Obves.f3d]
2026-04-10 созданы dxf для резки панелей обвеса
    [Ellic_Obves.f3d, dxfBreastPn.dxf, dxfFootPn.dxf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]
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2026-04-14 изменена структура папок
    [EllicV14ParasolidEng.x_t]
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2026-05-05 Заработала нормальный старт и крутит коленвал на 35 PWM стабильно и не резко
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2026-05-19 Добавлен система держателя энкодера
    [ReductorEncodera.f3d]
2026-05-19 Обновлен редуктор энкодера
    [ReductorEncodera.f3d]
2026-05-19 Редуктор вала сделан. Осталось кронштейн схемы энкодера
    [ReductorEncodera.f3d]
2026-05-20 собрал шестеренку вала энкодера
    [ReductorEncodera.f3d, RemenHoldera.stl, SpurValGear30.stl]
2026-05-20 Доработал шляпу вала энкодера
    [EncoderGear30.stl, HatEncGearVal.stl, ReductorEncodera.f3d]
2026-05-20 Рабочая сборка редуктора энокодера коленвала. Не очень удачно спроектирован Держатель вала вехней звездочки - поддержки все портят. Надо сделать сплошным и толщину 0.3мм
    [EncoderHolder.stl, HolderEncBody.stl, HolderEncoderaBody.stl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]
2026-06-09 Сделана DXF раскладка обвеса для лазера общим контуром. Сделан крнштейн для закреплени обвеса на траверсе.
    [Ellic_Obves.f3d, KronshtainObvesa.f3d, MasterObves.dxf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]
2026-06-09 Сделан стакан обвеса траверсы. Крепление на двутавриках
    [ConnectorsObvesTravers.stl, Ellic_Obves.f3d, StakanObvesaTravers.stl]
2026-06-10 Сделан стакан обвеса траверсы. отправлен на первую печать.
    [Ellic_Obves.f3d, StakanObvesaTravers.stl]
2026-06-11 Созал ответные части на кронштейны обвеса
    [Ellic_Obves.f3d]
2026-06-11 доработаны ответные части обвеса
    [Ellic_Obves.f3d]
2026-06-11 осталось сделать контакты рамы с ответными частями
    [Ellic_Obves.f3d]
2026-06-15 Собрал все ответные пластины
    [Ellic_Obves.f3d]
2026-06-15 сделаны все кронштейны обвеса
    [Ellic_Obves.f3d, KluvNizUgol.stl, KluvVerhrhFront.stl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]
2026-06-16 уточнение позиционирования боковой панели обвеса и креплений
    [Ellic_Obves.f3d]
2026-06-16 боковая панель стояла не на месте изза этого весь крепежь ее к рме был хрен знает где. я переставил боковую панель и в целом немного причесал крепеж ее к раме. но теперь фронтальны панели не стыкуютс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
    [Ellic_Obves.f3d]
2026-06-16 поправил крепеж, удаляю лишние скетчи
    [Ellic_Obves.f3d]
2026-06-16 держатель клюва
    [Ellic_Obves.f3d]
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2026-06-18 продвгаемся с обвесом
    [Body1.stl, Body1Norm.stl, BrestFront.stl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]
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2026-07-09 нстроены контроллеры моторов колес одрайв в firmware\STM32\MOTORDRIVERS, через Platformio Home подключны firmware\ESP32ELLIC\Experiments\EncoderMirror\platformio.ini по дефолту. С помощью ESP оба мот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
2026-07-14 ерешли на модульную структуру и импульсную поддержку. ок не удалось поборото шум энкодера as5600
2026-07-14 аботает следение мотора за энкодером. разнес в разные стороны земли моторов и энкодера. сделал геар рэтио 10,4 частота. Wire.setClock(100000)
2026-07-15 олеса настроены на одрайвтуле и работают нормально. есть немного треска на значениях удержания. пока остаим без внимания.
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2026-07-15 нормально работает. предстоит определить 0 при старте для правой ноги вверху и настроить вачдог чтобы при отключении питания esp моторы не неслись. https://chatgpt.com/s/t_6a577de5086881918359e34af7d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
2026-07-28 моторы работают, добавлена кнопка блютус. но иногда моторы проскакивают в обратную сторону
    [ReductorEncodera.f3d, SchemaHolderEncoder.stl]
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2026-08-27 управление моторами версия 2
    [EncoderGear30.stl, EncoderHolder.stl, EncoderHolder2.stl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]
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2026-09-04 исправленный конфиг стейт
2026-09-04 обновленная спецификация и вручную исправленный под нее код
    [ODriveUART.cpp]
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2026-10-01 Опубликован конфиг Одрайва
    [configODRIVE.txt]
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
